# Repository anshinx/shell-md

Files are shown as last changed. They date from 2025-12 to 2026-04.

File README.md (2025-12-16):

# Shell Eco-Marathon BLDC Motor Sürücü Kartı (Shell-MD)

Bu depo, **Shell Eco-Marathon** araçları için özel olarak tasarlanmış, STM32 tabanlı, yüksek performanslı 3-Faz BLDC motor sürücü kartının **KiCad** donanım tasarım dosyalarını içerir.

Proje, **Mitsuba M2096D** gibi yüksek verimli motorları sürmek ve araç telemetrisini yönetmek amacıyla geliştirilmiştir.

## 🚀 Öne Çıkan Özellikler

* **Güçlü İşlemci:** ARM Cortex-M3 tabanlı **STM32F205VGT6** (120MHz, 1MB Flash).
* **Yüksek Akım Kapasitesi:** Faz başına 4 adet paralel MOSFET (**4+4+4 Topolojisi**) ile düşük $R_{DS(on)}$ ve minimum ısınma.
* **Sağlam Gate Sürüşü:** **IRS21867S** High/Low Side sürücüler ve her MOSFET için ayrılmış Gate dirençleri ile parazitik osilasyon koruması.
* **Gelişmiş İletişim:**
    * **CAN Bus:** Araç içi haberleşme için izoleli **TJA1051** arayüzü.
    * **Bluetooth:** Telemetri ve mobil ayar için **HM-10** (BLE) desteği.
    * **USB Type-C:** Veri günlüğü ve konfigürasyon için USB 2.0 arayüzü.
* **Sensör Arayüzleri:** Hall Sensörleri (Gürültü filtreli), Gaz Pedalı (Potansiyometre), Fren ve Hız Sabitleme (Cruise) girişleri.

## 🛠 Donanım Özellikleri (Hardware Specs)

| Bileşen | Model / Değer | Açıklama |
| :--- | :--- | :--- |
| **MCU** | STM32F205VGT6 | Ana kontrolcü. |
| **MOSFET** | IAUS300N08S5N014  |**. |
| **Gate Driver** | IRS21867S | 2A High/Low Side Driver. |
| **CAN Transceiver** | TJA1051 | 5V beslemeli, yüksek hızlı CAN PHY. |
| **Bluetooth** | HM-10 / JDY-08 | UART üzerinden BLE haberleşmesi. |
| **USB** | Type-C (16-Pin) | CC dirençli, Device modunda çalışır. |
| **Besleme** | 12V & 3.3V | Harici regülatör girişi gerektirir. |

## 🔌 Pinout ve Bağlantılar

Kart üzerindeki kritik konnektör ve pin bağlantıları şöyledir:

### Motor & Güç
* **DC Bus:** 16S Batarya (~67V) girişi.
* **Faz Çıkışları:** Phase A, Phase B, Phase C (Vidalı Klemens).
* **Hall Sensörleri:** 5 Pin (5V, GND, H1, H2, H3) - RC Filtreli.

### Kontrol Arayüzleri
* **Gaz Pedalı:** Analog Giriş (0-3.3V) - `PA2`
* **Rejeneratif Fren:** Analog Giriş - `PA4`
* **Fren Anahtarı:** Dijital Giriş (Active Low) - `PE5`
* **Cruise Control:** Dijital Giriş (Active Low) - `PE6`

### Haberleşme
* **SWD:** Programlama ve Debug (`3V3`, `GND`, `SWDIO`, `SWCLK`).
* **CAN Bus:** Sonlandırma direnci (120Ω) jumper ile seçilebilir.
* **UART (Bluetooth):** `PC10` (TX) ve `PC11` (RX).

---
Anshinx

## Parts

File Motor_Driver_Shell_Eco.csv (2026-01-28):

Id | Designator | Footprint | Quantity | Designation | Supplier and ref
1 | C9 | C_1210_3225Metric_Pad1.33x2.70mm_HandSolder | 1 | 1uF
2 | R4 | R_0603_1608Metric_Pad0.98x0.95mm_HandSolder | 1 | 86.6K
3 | C29,C30 | C_0603_1608Metric_Pad1.08x0.95mm_HandSolder | 2 | 22pF
4 | D3 | LED_D1.8mm_W3.3mm_H2.4mm | 1 | LED_R
5 | C6,C4,C5 | C_Radial_D6.3mm_H11.0mm_P2.50mm | 3 | 10uF / 100V
6 | C54,C37,C26,C56,C48,C36,C50,C51,C53,C41,C47,C24,C18,C21,C20,C23 | C_0603_1608Metric_Pad1.08x0.95mm_HandSolder | 16 | 100nF
7 | C16 | C_0603_1608Metric_Pad1.08x0.95mm_HandSolder | 1 | 15nF
8 | C39,C40,C88,C90,C57 | C_Rect_L7.2mm_W3.5mm_P5.00mm_FKS2_FKP2_MKS2_MKP2 | 5 | 4.7uF
9 | R22 | R_0603_1608Metric_Pad0.98x0.95mm_HandSolder | 1 | 120R
10 | J7,J10,J12,J3 | PinSocket_1x02_P2.00mm_Horizontal | 4 | Conn_01x02
11 | R15,R14,R10,R25,R9,R24,R16 | R_0603_1608Metric_Pad0.98x0.95mm_HandSolder | 7 | 4.7K
12 | Q16,Q19,Q18,Q7,Q20,Q6,Q21,Q9,Q15,Q8,Q14,Q17 | TRANS_IAUS300N08S5N014ATMA1 | 12 | IAUS300N08S5N0
13 | C33,C35,C34 | C_0603_1608Metric_Pad1.08x0.95mm_HandSolder | 3 | 10nF
14 | C12,C14 | C_0603_1608Metric_Pad1.08x0.95mm_HandSolder | 2 | 2.2uF
15 | J4 | PinSocket_1x02_P2.00mm_Vertical | 1 | Conn_01x02
16 | R53,R54 | R_0603_1608Metric_Pad0.98x0.95mm_HandSolder | 2 | 22
17 | R31,R35,R30,R36,R55,R27,R56,R34,R33,R26,R32,R57,R28,R13,R37 | R_0805_2012Metric_Pad1.20x1.40mm_HandSolder | 15 | 10R
18 | R64,R63,R69,R58,R59,R68 | R_0603_1608Metric_Pad0.98x0.95mm_HandSolder | 6 | 10k
19 | C10 | C_0603_1608Metric_Pad1.08x0.95mm_HandSolder | 1 | .1uF
20 | S1 | LES50NP | 1 | LES50-NP
21 | R12 | R_Axial_DIN0207_L6.3mm_D2.5mm_P7.62mm_Horizontal | 1 | 260
22 | C82,C84,C86 | C_0402_1005Metric_Pad0.74x0.62mm_HandSolder | 3 | 100nF
23 | R3 | R_0603_1608Metric_Pad0.98x0.95mm_HandSolder | 1 | 100K
24 | C8 | C_Disc_D10.5mm_W5.0mm_P10.00mm | 1 | 100nF
25 | C27 | C_0805_2012Metric_Pad1.18x1.45mm_HandSolder | 1 | 10uf
26 | J9,J8 | PinSocket_1x03_P2.00mm_Horizontal | 2 | Conn_01x03
27 | U1 | LQFP-100_14x14mm_P0.5mm | 1 | STM32F205VGTx
28 | R67,R39,R62,R29,R65,R60 | R_0402_1005Metric_Pad0.72x0.64mm_HandSolder | 6 | 10
29 | BZ1 | Buzzer_12x9.5RM7.6 | 1 | Buzzer
30 | C11,C25,C13 | C_0603_1608Metric_Pad1.08x0.95mm_HandSolder | 3 | 1uF
31 | D1 | D_A-405_P10.16mm_Horizontal | 1 | SR5100
32 | C28 | C_Disc_D10.5mm_W5.0mm_P5.00mm | 1 | 100nF
33 | R51,R52 | R_0603_1608Metric_Pad0.98x0.95mm_HandSolder | 2 | 5.1K
34 | U8 | SOIC-8_3.9x4.9mm_P1.27mm | 1 | TJA1051T
35 | C1,C2,C3 | C_Radial_D16.0mm_H31.5mm_P7.50mm | 3 | 680uF / 100V
36 | U5,U13,U11 | SOT-23-8_Handsoldering | 3 | INA241A2
37 | U12 | SOT-23-6 | 1 | TMP101
38 | Q1 | SOT-23 | 1 | BC817
39 | C45 | C_1210_3225Metric_Pad1.33x2.70mm_HandSolder | 1 | 100nF
40 | U9,U10,U6 | SOIC-8_3.9x4.9mm_P1.27mm | 3 | IRS21867S
41 | R6 | R_0603_1608Metric_Pad0.98x0.95mm_HandSolder | 1 | 46k
42 | C7 | CP_Radial_D10.0mm_P5.00mm | 1 | 470uF/25V
43 | C38,C55,C52,C49,C19,C22,C46 | C_0603_1608Metric_Pad1.08x0.95mm_HandSolder | 7 | 10uF
44 | D2 | D_DO-35_SOD27_P7.62mm_Horizontal | 1 | 1N4148
45 | U4 | SOT-23-3 | 1 | XC6206 - 3V3
46 | SW1,SW2 | SW_PUSH_6mm_H8mm | 2 | SW_Push
47 | Y1 | Crystal_HC18-U_Vertical | 1 | 8MHz
48 | R8 | R_0402_1005Metric_Pad0.72x0.64mm_HandSolder | 1 | 10K
49 | C89 | C_Rect_L7.2mm_W3.5mm_P5.00mm_FKS2_FKP2_MKS2_MKP2 | 1 | 100nF
50 | R1 | R_Axial_DIN0207_L6.3mm_D2.5mm_P15.24mm_Horizontal | 1 | 220K
51 | R21 | R_0603_1608Metric_Pad0.98x0.95mm_HandSolder | 1 | 260
52 | R20 | R_Axial_DIN0207_L6.3mm_D2.5mm_P7.62mm_Horizontal | 1 | 4.7K
53 | R18,R17,R19 | R_0603_1608Metric_Pad0.98x0.95mm_HandSolder | 3 | 2.2K
54 | C32,C31 | C_0603_1608Metric_Pad1.08x0.95mm_HandSolder | 2 | 2.2µF
55 | L1 | L_1210_3225Metric_Pad1.42x2.65mm_HandSolder | 1 | 220uH 2A
56 | J2 | PinSocket_1x05_P2.00mm_Vertical | 1 | HALL INPUT
57 | R2 | R_Axial_DIN0207_L6.3mm_D2.5mm_P10.16mm_Horizontal | 1 | 1K
58 | C87,C83,C85 | C_0402_1005Metric_Pad0.74x0.62mm_HandSolder | 3 | 10nF
59 | J13 | PinSocket_1x02_P2.00mm_Horizontal | 1 | OUTSIDE LED
60 | R5 | R_0603_1608Metric_Pad0.98x0.95mm_HandSolder | 1 | 10K
61 | FB1 | R_0805_2012Metric_Pad1.20x1.40mm_HandSolder | 1 | 12R
62 | J6 | PinSocket_1x06_P1.27mm_Vertical | 1 | Conn_01x06
63 | R7,R50 | R_Axial_DIN0207_L6.3mm_D2.5mm_P7.62mm_Horizontal | 2 | 10K
64 | R11 | R_Axial_DIN0207_L6.3mm_D2.5mm_P7.62mm_Horizontal | 1 | 1K
65 | R23 | R_0603_1608Metric_Pad0.98x0.95mm_HandSolder | 1 | 100
66 | U2 | SOIC-8-1EP_3.9x4.9mm_P1.27mm_EP2.95x4.9mm_Mask2.71x3.4mm_ThermalVias | 1 | LM5017MR
67 | U3 | SOT-23-5 | 1 | AP2204K-5.0
68 | J11 | USB_C_Receptacle_GCT_USB4105-xx-A_16P_TopMnt_Horizontal | 1 | USB_C_Receptacle
69 | C15 | C_0603_1608Metric_Pad1.08x0.95mm_HandSolder | 1 | 3.3nF
70 | J5 | PinSocket_1x04_P1.27mm_Vertical | 1 | Conn_01x04
71 | C17 | C_1210_3225Metric_Pad1.33x2.70mm_HandSolder | 1 | 47uF
72 | C65,C66,C78,C81,C80,C79,C70,C63,C73,C74,C72,C64,C67,C71,C77 | C_0805_2012Metric_Pad1.18x1.45mm_HandSolder | 15 | 100nF
73 | C62,C76,C61,C69,C68,C75 | C_1210_3225Metric_Pad1.33x2.70mm_HandSolder | 6 | 10uF
74 | D4,D7,D5 | D_SMA | 3 | US1M
75 | R70,R61,R66,R71,R38,R72 | R_2512_6332Metric_Pad1.40x3.35mm_HandSolder | 6 | 1mR
76 | C58,C59,C60 | C_0805_2012Metric_Pad1.18x1.45mm_HandSolder | 3 | 100uf
77 | J1 | PinSocket_1x04_P2.00mm_Vertical | 1 | I2C EKRAN

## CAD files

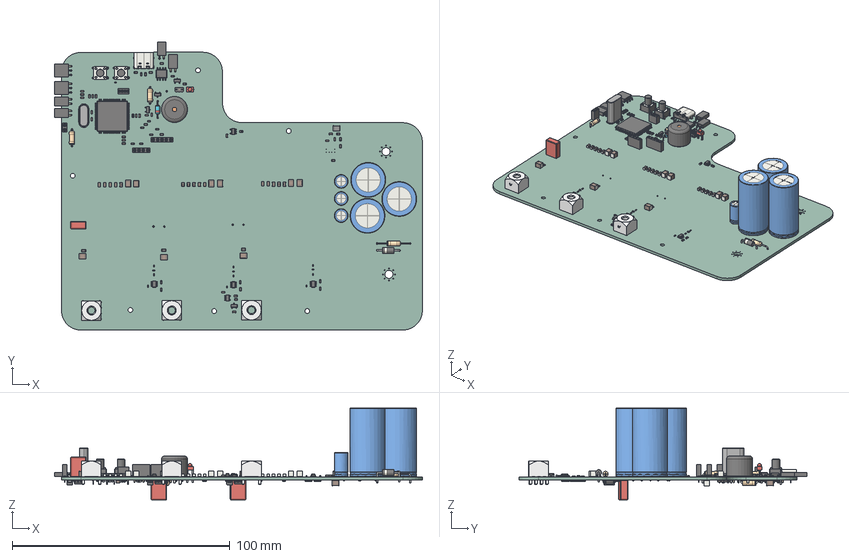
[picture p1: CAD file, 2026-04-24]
Motor_Driver_Shell_Eco.step
169.1 x 132.4 x 42.2 mm
R_0603_1608Metric x 26
R_0402_1005Metric x 7
C_0603_1608Metric x 37
C_1210_3225Metric x 11
Buzzer_12x9.5RM7.6
SOT-23-8 x 3
SW_PUSH_6mm_H8mm x 2
C_0805_2012Metric x 16
LED_D1.8mm_W3.3mm_H2.4mm
C_Radial_D16.0mm_H31.5mm_P7.50mm x 3
SOT-23-3 x 2
PinSocket_1x02_P2.00mm_Horizontal x 4
SOT-23-5 x 2
R_0805_2012Metric x 17
PinSocket_1x03_P2.00mm_Horizontal x 2
L_1210_3225Metric
C_0402_1005Metric x 6
R_Axial_DIN0207_L6.3mm_D2.5mm_P7.62mm_Horizontal x 3
C_Radial_D6.3mm_H11.0mm_P2.50mm x 3
PinHeader_1x03_P1.27mm_Vertical
PinSocket_1x04_P2.00mm_Vertical
PinSocket_1x05_P2.00mm_Vertical
SOT-23 x 2
Redcube x 3
Logo x 3
PinSocket_1x04_P1.27mm_Vertical
C_Rect_L7.2mm_W3.5mm_P5.00mm_FKS2_FKP2_MKS2_MKP2 x 3
D_A-405_P10.16mm_Horizontal
D_DO-35_SOD27_P7.62mm_Horizontal
PinSocket_1x02_P2.00mm_Vertical
Crystal_HC18-U_Vertical
LQFP-100_14x14mm_P0.5mm
USB_C_Receptacle_GCT_USB4105-xx-A_16P_TopMnt_Horizontal
SOIC-8_3.9x4.9mm_P1.27mm x 4
R_Axial_DIN0207_L6.3mm_D2.5mm_P15.24mm_Horizontal
R_2512_6332Metric x 6
D_SMA x 3
R_1210_3225Metric
Motor_Driver_Shell_Eco_PCB

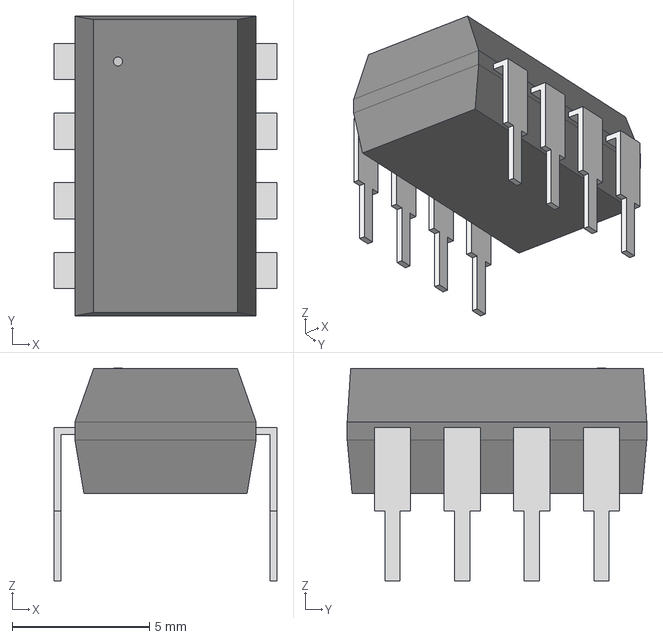
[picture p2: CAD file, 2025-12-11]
DIP-8_STM.step
8.13 x 10.9 x 7.75 mm

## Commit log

2025-12-05 MCU PAGE FINISHED
    [mcu.kicad_sch]
2025-12-05 Add pinout table and voltage regulation details to README
    Added detailed pinout table and power regulation information.
2025-12-05 Update README with connector details
    Added connector information for LSIDE and R SIDE.
2025-12-05 Update connector information in README.md
2025-12-06 SCHEMATIC DONE - NEED REVIEW
    [Motor_Driver_Shell_Eco.kicad_pcb, Motor_Driver_Shell_Eco.kicad_sch, hall_input.kicad_sch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]
2025-12-06 Update README
    Removed security and assembly warnings, and updated SWD section.
2025-12-06 LATEST UPDATES
    [Motor_Driver_Shell_Eco.kicad_pcb, mcu.kicad_sch, mosfets.kicad_sch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]
2025-12-11 Fet Drivers olarak IRS21867S, MOSFET olarak IAUS300N08S5N014 değiştirildi. Decoupler kısmı değiştirildi, (paraziter direnci arttırıldı.) buzzer düzeltildi ve utility kısmına alındı. CAN-BUS bitti. LD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
    [DIP-8_STM.step, Motor_Driver_Shell_Eco.kicad_pcb, hall_input.kicad_sch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]
2025-12-12 Update gate driver and MOSFET models in README
2025-12-16 update Current sense
    [Motor_Driver_Shell_Eco.kicad_pcb, fetcaps.kicad_sch, hall_input.kicad_sch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]
2025-12-22 update: revised label
    [Motor_Driver_Shell_Eco.kicad_pcb, Motor_Driver_Shell_Eco.kicad_sch, mcu.kicad_sch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]
2025-12-22 changes to pcb and footprints
    [Motor_Driver_Shell_Eco.kicad_pcb, vin.kicad_sch]
2025-12-28 LAST I HOPE
    [Motor_Driver_Shell_Eco.csv, Motor_Driver_Shell_Eco.kicad_pcb, mcu.kicad_sch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]
2026-01-28 son update
    [Motor_Driver_Shell_Eco-B_Cu.gbr, Motor_Driver_Shell_Eco-B_Mask.gbr, Motor_Driver_Shell_Eco-B_Paste.gbr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]
2026-02-18 bit artık
    [Motor_Driver_Shell_Eco.kicad_pcb, Motor_Driver_Shell_Eco.kicad_sch, phase_c_fet.kicad_sch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]
2026-02-26 MD DONE IHOPE
    [Motor_Driver_Shell_Eco.kicad_pcb, mosfets.kicad_sch]
